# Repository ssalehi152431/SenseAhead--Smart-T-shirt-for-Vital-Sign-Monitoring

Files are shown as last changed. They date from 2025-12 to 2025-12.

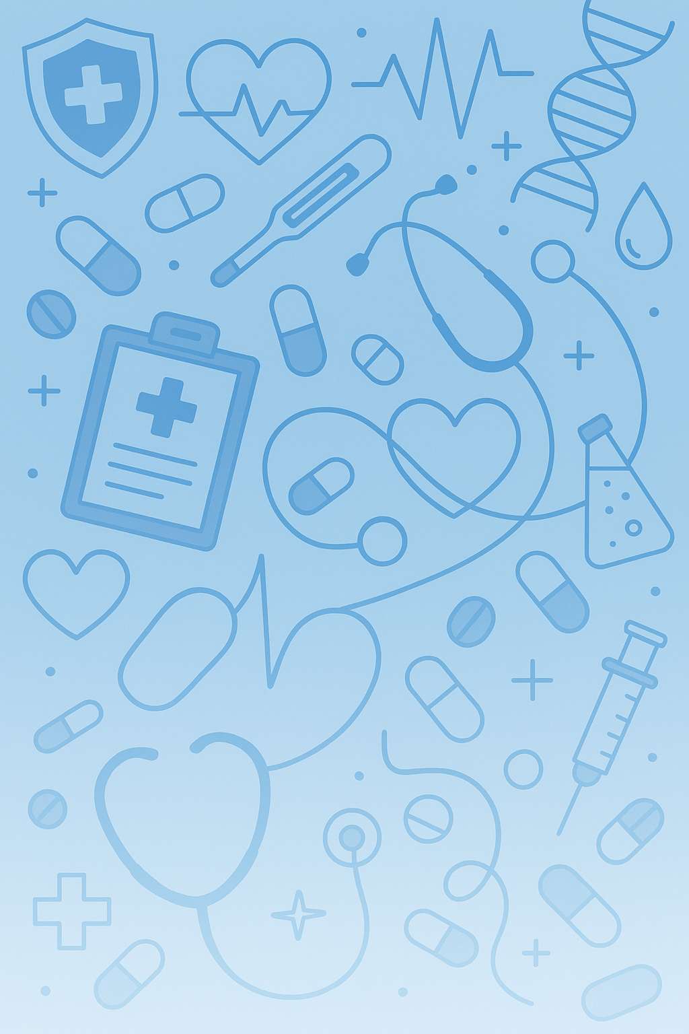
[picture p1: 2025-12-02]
webpage/images/background.png

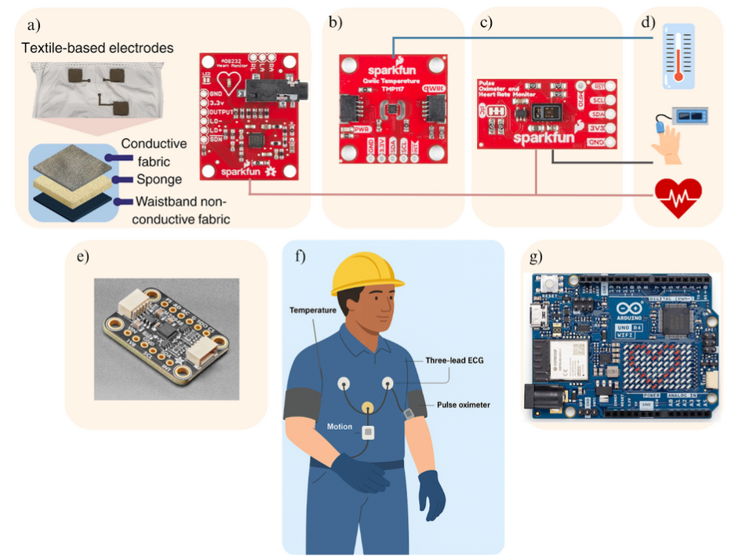
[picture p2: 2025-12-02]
images/Fig 3.png

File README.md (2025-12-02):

# SenseAhead Smart Shirt for Occupational Health
# VSM-3 Vital Sign Monitoring System

This repository contains all design, firmware, hardware, and web application files required to run the VSM‑3 wearable system, which collects **ECG, SpO2, IMU, and temperature data** and displays them on a local web dashboard.

## Our Approach
our approach



## Final Product

Tshirt _2
Tshirt _1
Data_collection

---

## 📦 Project Folder Structure

```
V3/
│
├── Bill_of_Materials.xlsx
│
├── CAD Files/                 → 3D printable enclosure components
│   ├── Arduino_ICM_bottom_v5.step
│   ├── Arduino_ICM_top_v5.step
│   ├── MAX_bottom_v2.step
│   ├── MAX_top_v4.step
│   ├── TMP_bottom_v2.step
│   ├── TMP_top_v2.step
│
├── web_arduino_2/             → Arduino firmware for vital-sign sensors
│   └── web_arduino_2.ino
│
└── webpage/                   → Local-only Web Dashboard (no Firebase needed)
    ├── export/
    ├── functions/
    ├── images/
    ├── node_modules/
    ├── public/
    ├── .firebaserc
    ├── .gitignore
    ├── firebase.json
    ├── firestore.indexes.json
    ├── firestore.rules
    ├── package.json
    └── package-lock.json
```

---

# How to Run the VSM‑3 System (USER GUIDE)

This guide explains how **any user** can run the system locally on their laptop and collect vital‑sign data from the wearable shirt.

---

# 1️⃣ Hardware Setup (Wearable Shirt)

### Required Components
- Arduino UNO R4 WiFi  
- MAX30101 (SpO₂ + HR)  
- AD8232 (ECG)  
- TMP117 (Temperature)  
- ICM‑20948 (9‑axis IMU)  
- Jumper wires  
- Enclosure 3D printed parts (from CAD folder)  
- Shirt with embedded sensors (as designed by team)

### Assembly Overview
1. Attach all sensors to the Arduino using Qwiic/I2C and analog ECG connection.  
2. Mount sensors inside the enclosure parts (CAD folder).  
3. Position electrodes on the chest and tighten straps.  
4. Power the system via USB cable to the laptop.

---

# 2️⃣ Upload Arduino Code

1. Open **Arduino IDE**.
2. Open:

```
web_arduino_2/web_arduino_2.ino
```

3. Scroll to the section:

```cpp
//=======Wi fi config========
const char* STA_SSID = "Salehin";
const char* STA_PASS = "GGunited";
```

Change these values to match your **hotspot name + password**.

4. Connect Arduino UNO R4 WiFi with USB.

5. Click:

✔ **Verify**  
✔ **Upload**

6. Open **Serial Monitor @ 115200 baud** and confirm you see lines like:

```
ECG=700   Thr=400   motionScore=0.02   motionQuality=GOOD
```

This confirms the shirt is sending sensor data.

---

# 3️⃣ Launch the Web Dashboard (Local Mode)

The dashboard is located at:

```
V3/webpage/public/index.html
```

### To open the dashboard:

1. Open VS Code  
2. Install the extension **Live Server**
3. Right‑click:

```
webpage/public/index.html
```

4. Select **"Open With Live Server"**

Your browser will open:

```
http://127.0.0.1:5500/webpage/public/index.html
```

---

# 4️⃣ Create User Account (Local Authentication)

1. On the dashboard login page, select **“Create account”**  
2. Enter:
   - Name  
   - Email  
   - Password  
3. Log in  
4. Your dashboard loads with:

- ACC  
- GYR  
- TEMP  
- SpO₂  
- HR  
- ECG waveform (real‑time)  

**This works fully offline (local Firestore emulator).**

---

# 5️⃣ Start Collecting Data

With Arduino running AND dashboard open:

✔ ECG plots appear  
✔ Temperature updates  
✔ SpO₂ shows when finger sensor works  
✔ HR from ECG is averaged  
✔ Motion score reflects IMU activity

---

# 6️⃣ Where Is Data Stored?

Even without Firebase, the dashboard stores data in:

```
webpage/export/
```

If Firebase is connected later, the same data is pushed to Firestore.

---

# 🛠 Developer Notes (for the team)

### If deploying Firebase Functions again:
Only the **project owner** can run:

```
firebase deploy --only functions
```

Other teammates need IAM permission  
**“Service Account User”**  
in Google Cloud.

Normal users running data collection **do NOT need Firebase**.

---

# 👥 Authors

- Artemis Badger  
- Luisa Chavez  
- Marc Dobos  
- Sultanus Salehin  
- Irem Yunculer

---

# 📄 License
This project is for educational use under ECE‑522 (NC State University).

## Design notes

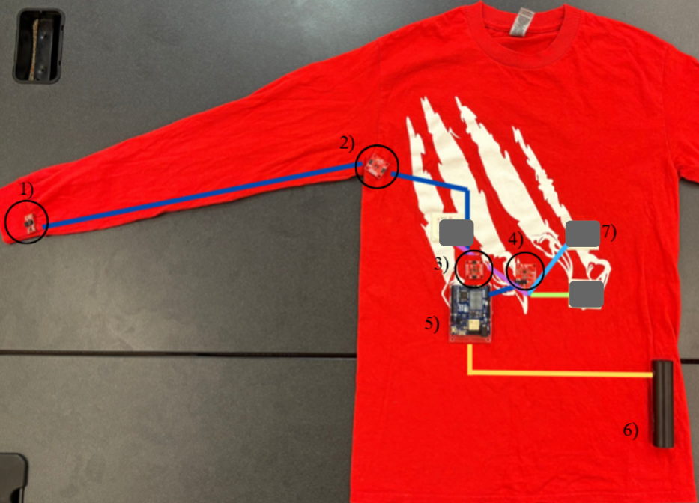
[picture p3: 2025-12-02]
images/Tshirt _1.png

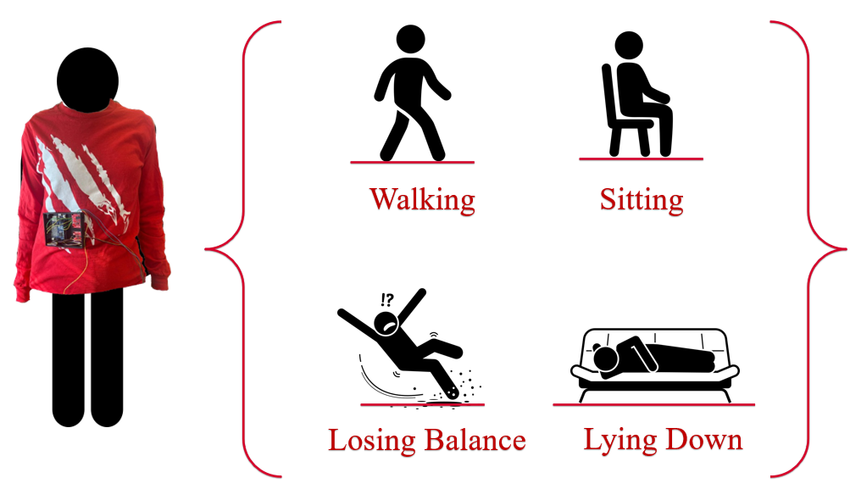
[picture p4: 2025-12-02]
images/Data_collection.png

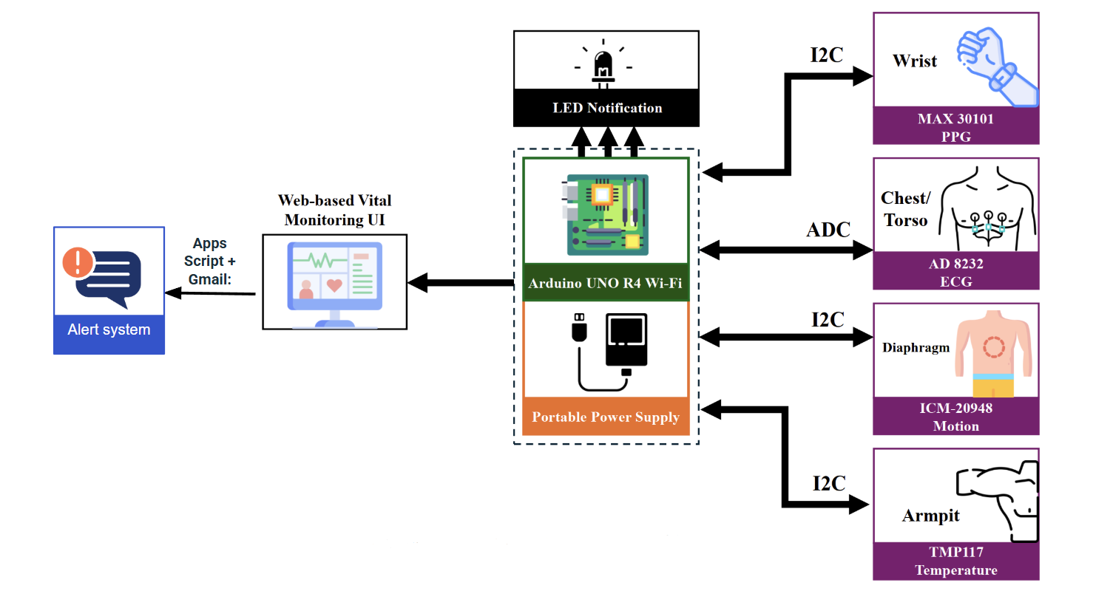
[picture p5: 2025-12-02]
images/our approach.png

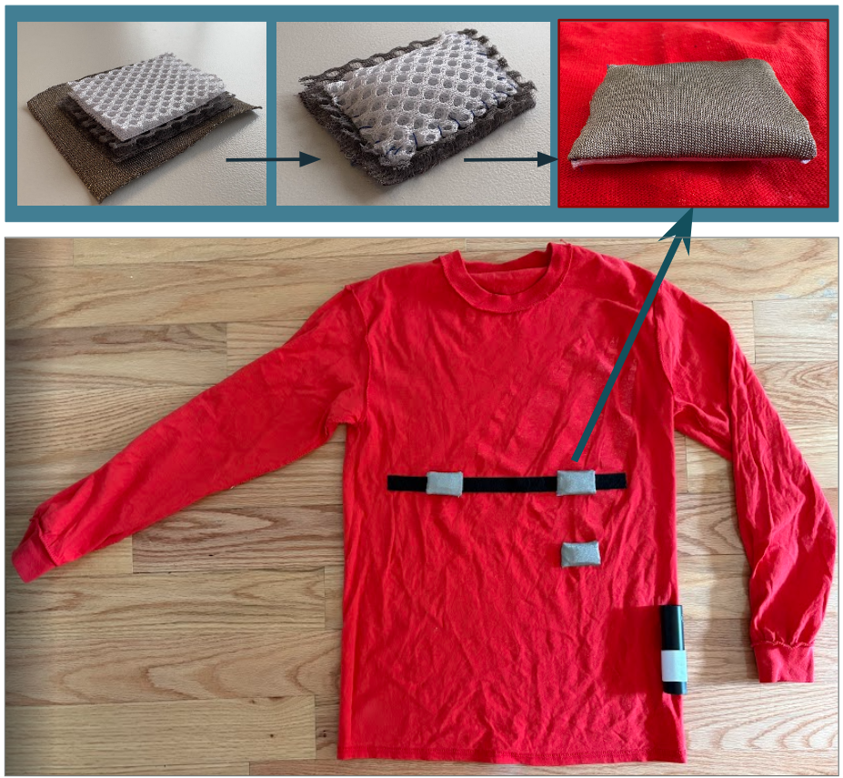
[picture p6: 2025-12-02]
images/Tshirt _2.png

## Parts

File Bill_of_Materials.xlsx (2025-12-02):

VSM-3 Final Bill of Materials
No. | Item Name | Vendor | Vendor Part # | Quantity | Cost per item | Link to Item | Total cost | Notes
1 | AD8232 Heart Rate Monitor | Sparkfun | SEN-12650 | 1 | $24.41 | SparkFun Single Lead Heart Rate Monitor - AD8232 - SparkFun Electronics (https://www.sparkfun.com/sparkfun-single-lead-heart-rate-monitor-ad8232.html) | $24.41
2 | TMP117 Temperature Sensor | Sparkfun | SEN-15850 | 1 | $16.95 | SparkFun High Precision Temperature Sensor - TMP117 (Qwiic) - SparkFun Electronics (https://www.sparkfun.com/sparkfun-high-precision-temperature-sensor-tmp117-qwiic.html) | $16.95
3 | MAX30101 & MAX32664 PPG Sensor | Sparkfun | SEN-15219 | 1 | $48.95 | SparkFun Pulse Oximeter and Heart Rate Sensor - MAX30101 & MAX32664 (Qwiic) - SparkFun Electronics (https://www.sparkfun.com/sparkfun-pulse-oximeter-and-heart-rate-sensor-max30101-max32664-qwiic.html) | $48.95
4 | ICM 20948 9DoF IMU | Sparkfun | SEN-15335 | 1 | $21.95 | SparkFun 9DoF IMU Breakout - ICM-20948 (Qwiic) - SparkFun Electronics (https://www.sparkfun.com/sparkfun-9dof-imu-breakout-icm-20948-qwiic.html) | $21.95
5 | Flexible Qwiix Cable 500mm | Sparkfun | PRT-17257 | 3 | $2.75 | Flexible Qwiic Cable - 500mm - SparkFun Electronics (https://www.sparkfun.com/flexible-qwiic-cable-500mm.html) | $8.25
6 | Jumper Wires M/M | Sparkfun | PRT-09387 | 1 | $4.95 | Jumper Wires Premium 12" M/M Pack of 10 - SparkFun Electronics (https://www.sparkfun.com/jumper-wires-premium-12-m-m-pack-of-10.html) | $4.95
7 | Silver-coated fabric | Amazon | MATYASIGO-US | 1 (dimensions: 0.5mx1.5m) | $27.46 | Amazon.com: silver-coated fabric (https://www.amazon.com/Knitting-Conductive-Radiation-Maternity-0-5MX1-5M/dp/B0B928YJY3) | $27.46
8 | Arduino UNO R4 WiFi | Amazon | ABX00087 | 1 | $27.50 | Amazon.com: Arduino UNO R4 WiFi [ABX00087] – Renesas RA4M1 + ESP32-S3, Wi-Fi, Bluetooth, USB-C, CAN, 12-bit DAC, OP AMP, Qwiic Connector, 12x8 LED Matrix for Advanced IoT & Embedded Projects : Electronics (https://www.amazon.com/Arduino-UNO-WiFi-ABX00087-Bluetooth/dp/B0C8V88Z9D) | $27.50
9 | USB to DC Power Charging Cable | Amazon | USB-DC-001 | 1 | $7.98 | Amazon.com: USB to DC Power Charging Cable with 12pcs DC Barrel Jack Universal Laptop Power Adapter Tips USB 2.0 to DC 5.5x2.1mm Plug Micro USB Type-C Connector Compatible Laptop Camera & More : Electronics (https://www.amazon.com/Charging-Universal-5-5x2-1mm-Connector-Compatible/dp/B0BXPXZMSP) | $7.98
10 | 15000mAh Portable Power Bank | Amazon | P11 | 1 | $12.34 | Amazon.com: LOVELEDI Portable Charger 2-Pack 15000mAh Power Bank Dual USB and Type-C Output 5V3.1A Fast Charger Battery Pack for iPhone 16 15 14 13 12 X Samsung S24 S23 Google iPad etc (Light Black and White) : Cell Phones & Accessories (https://www.amazon.com/dp/B0C4JTVXSK?sp_csd=d2lkZ2V0TmFtZT1zcF9kZXRhaWwy) | $12.34
11 | 3 Rolls Sewing Stretch Elastic Band Spool, 3/5, 1, 1-1/2 Inch in Width, 5.5 Yards/Roll (White) | Amazon | SUNMNS | 1 White Set of 3 rolls (3/5, 1 and 1-1/2 Inch in Width, 5.5 Yards/Roll) | $11.99 | https://www.amazon.com/Sunmns-Rolls-Sewing-Stretch-Elastic/dp/B07J44MP4L | $11.99
12 | SparkFun Photodetector Breakout - MAX30101 | Sparkfun | SEN-16474 | 1 | $34.39 | https://www.sparkfun.com/sparkfun-photodetector-breakout-max30101-qwiic.html#content-features | $34.39
 |  |  |  |  |  | Grand Total: | $247.12

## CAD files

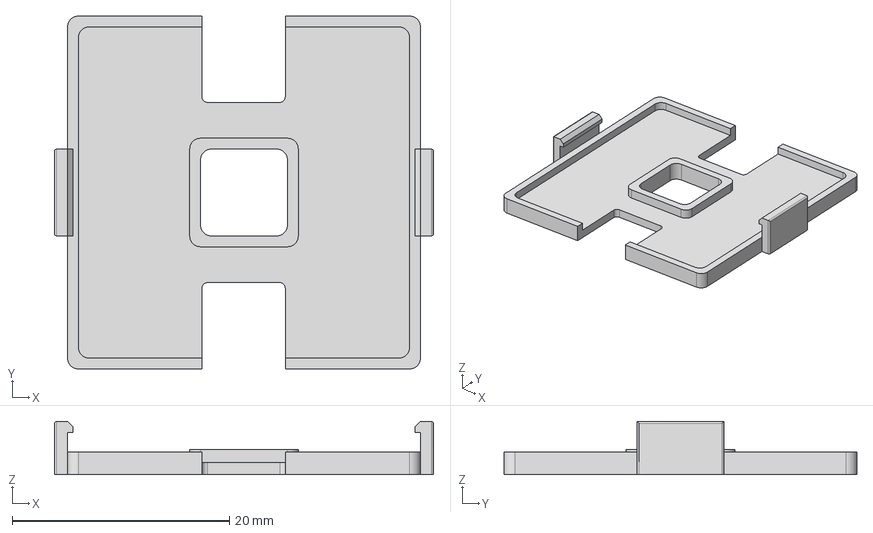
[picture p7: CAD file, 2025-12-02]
CAD Files/TMP_top_v2.step
34.9 x 32.5 x 4.90 mm

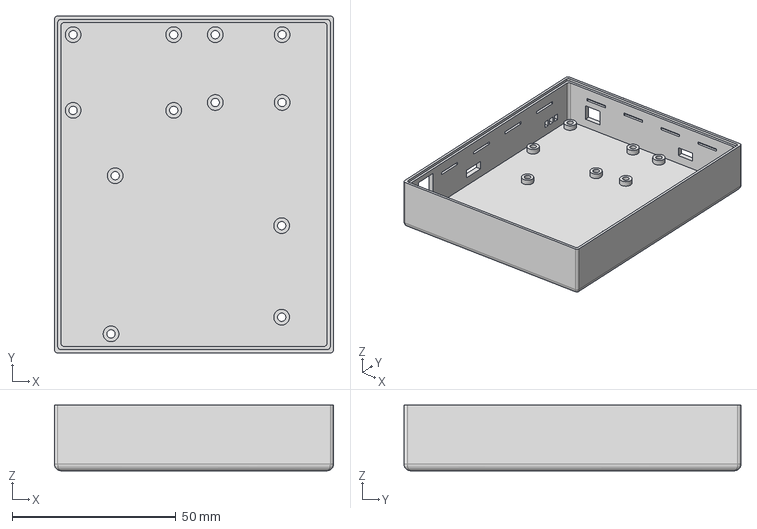
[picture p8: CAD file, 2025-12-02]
CAD Files/Arduino_ICM_bottom_v5.step
85.2 x 102.8 x 20.0 mm

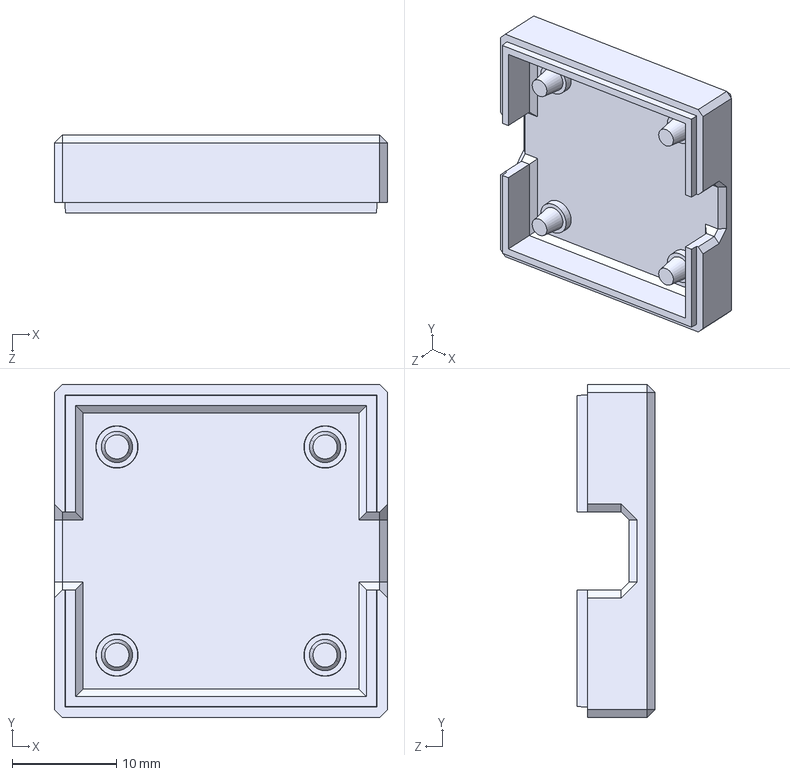
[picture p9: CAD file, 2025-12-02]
CAD Files/MAX_bottom_v2.STEP
32.0 x 32.0 x 7.50 mm

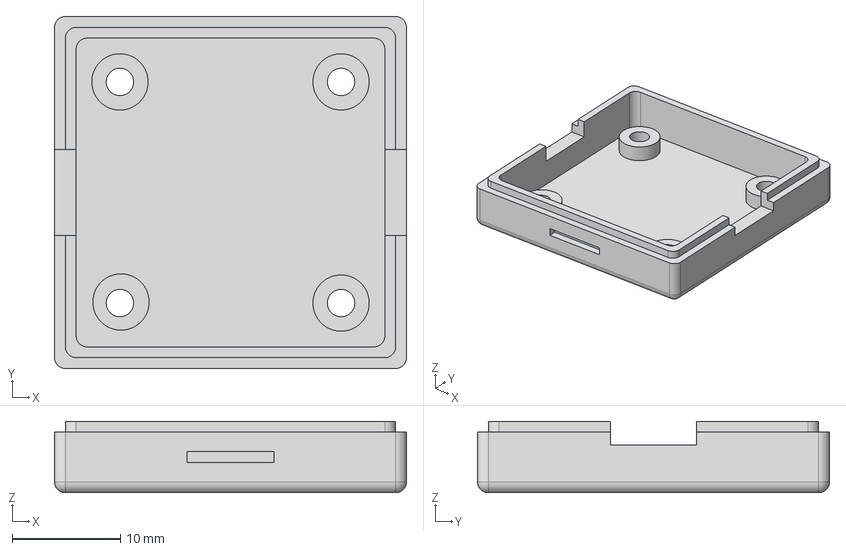
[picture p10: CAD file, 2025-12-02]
CAD Files/TMP_bottom_v2.step
32.5 x 32.5 x 6.60 mm

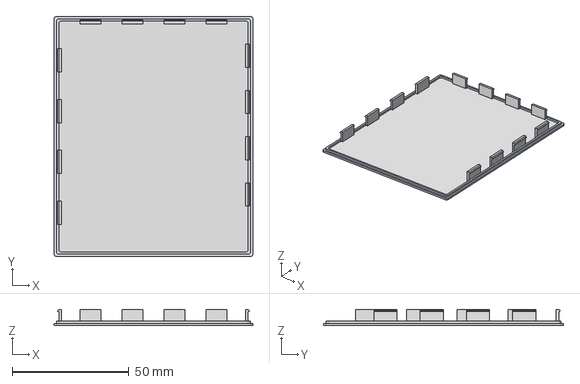
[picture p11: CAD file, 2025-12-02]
CAD Files/Arduino_ICM_top_v5.step
85.2 x 102.8 x 7.00 mm

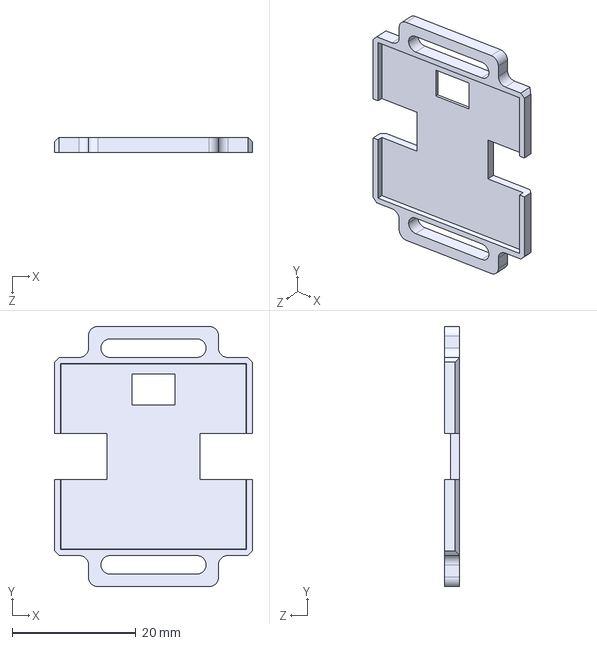
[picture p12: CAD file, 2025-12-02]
CAD Files/MAX_top_v4.STEP
32.0 x 42.0 x 2.50 mm

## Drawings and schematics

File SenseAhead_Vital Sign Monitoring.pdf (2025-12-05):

# SenseAhead Smart Shirt: Wearable Vital Sign Monitoring for Occupational Health and Safety

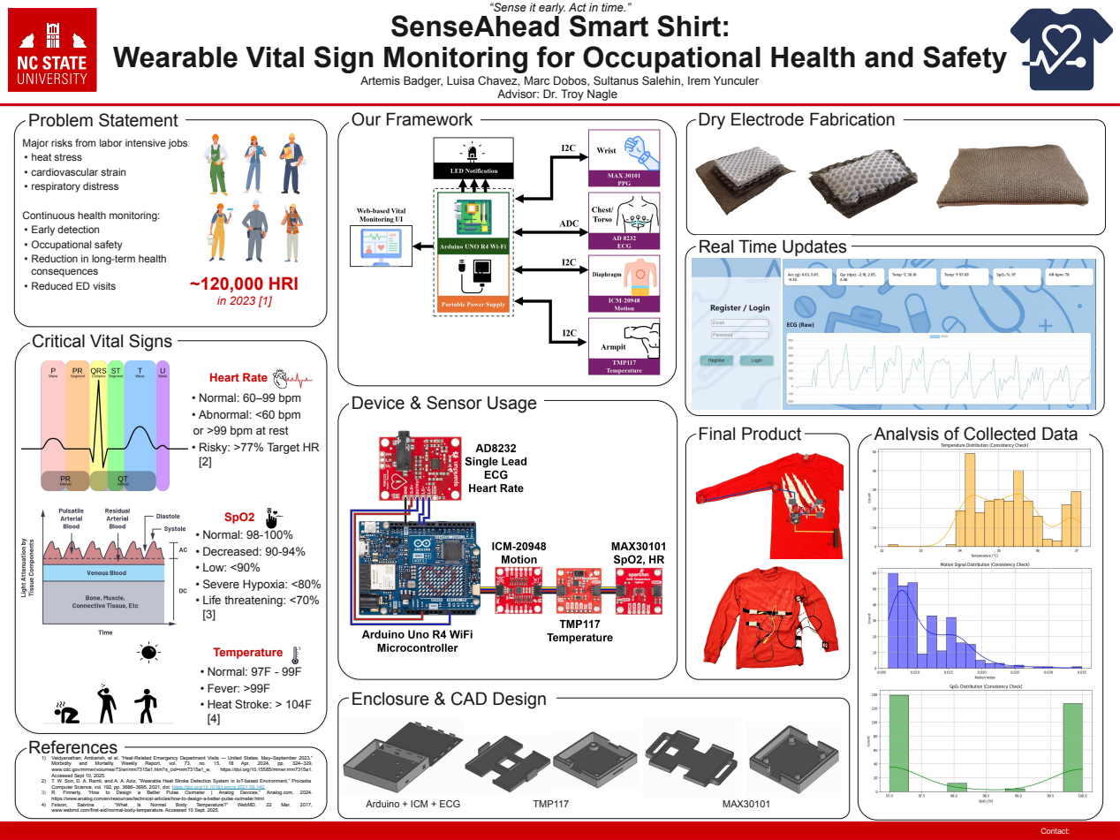
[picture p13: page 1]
Arduino + ICM + ECG; TMP117; MAX30101; Contact:; Problem Statement; Our Framework; References; Final Product; SpO2; Temperature; • Normal: 97F - 99F • Fever: >99F • Heat Stroke: > 104F [4]; ~120,000 HRI; • Normal: 98-100% • Decreased: 90-94% • Low: <90% • Severe Hypoxia: <80% • Life threatening: <70% [3]; Morbidity; and; Mortality; Weekly; Report,; vol.; Apr.; www.cdc.gov/mmwr/volumes/73/wr/mm7315a1.htm?s_cid=mm7315a1_w,; https://doi.org/10.15585/mmwr.mm7315a1.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

“Sense it early. Act in time.”

Artemis Badger, Luisa Chavez, Marc Dobos, Sultanus Salehin, Irem Yunculer

Advisor: Dr. Troy Nagle

Dry Electrode Fabrication

Major risks from labor intensive jobs:
• heat stress
• cardiovascular strain
• respiratory distress

Continuous health monitoring:
• Early detection
• Occupational safety
• Reduction in long-term health
consequences
• Reduced ED visits

Real Time Updates

Critical Vital Signs

Heart Rate
• Normal: 60–99 bpm
• Abnormal: <60 bpm
or >99 bpm at rest
• Risky: >77% Target HR

Device & Sensor Usage

Analysis of Collected Data

Enclosure & CAD Design

1) Vaidyanathan, Ambarish, et al. “Heat-Related Emergency Department Visits — United States, May–September 2023.”
Accessed Sept 10, 2025.
2) T. W. Son, D. A. Ramli, and A. A. Aziz, “Wearable Heat Stroke Detection System in IoT-based Environment,” Procedia
https://www.analog.com/en/resources/technical-articles/how-to-design-a-better-pulse-oximeter.html
www.webmd.com/first-aid/normal-body-temperature. Accessed 10 Sept. 2025.

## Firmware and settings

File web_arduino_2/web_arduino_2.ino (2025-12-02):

#include <WiFiS3.h>
#include <WiFiSSLClient.h>
#include <ArduinoGraphics.h>
#include <Wire.h>
#include <SparkFun_TMP117.h>
#include <ICM_20948.h>
#include <MAX30105.h>
#include "spo2_algorithm.h"   
#include <math.h>
#include <string.h>

//=======Wi fi config========
const char* STA_SSID = "iPhone";
const char* STA_PASS = "5859Irem";

//=======Cloud function===================
const char* CLOUD_HOST = "us-central1-vsm3-741ac.cloudfunctions.net";
const char* CLOUD_INGEST_PATH = "/api/ingest";
const uint16_t HTTPS_PORT = 443;

WiFiServer server(80);

TMP117 tmp117;
ICM_20948_I2C icm;
MAX30105 max30101;
float lastTempC = NAN;
bool max30101_ok = false;

//======ECG =======
const int PIN_ECG_OUT  = A0;
const int PIN_LO_PLUS  = 10;
const int PIN_LO_MINUS = 11;

//=======ECG configuration=======
const float FS_HZ = 250.0f;
const unsigned long TS_US = (unsigned long)(1000000.0f / FS_HZ);
const size_t ECG_BATCH = 250; //1 second per batch
uint16_t ecgBuf[ECG_BATCH];
size_t ecgIdx = 0;
unsigned long next_us = 0;

// ====== ECG detection ======
int ecgValue = 0;
int ecgMin = 1023;
int ecgMax = 0;
int ecgThreshold = 400;

unsigned long lastThreshUpdate = 0;
const unsigned long ECG_WINDOW = 1000;  

unsigned long lastBeatECG = 0;
float bpmECG = 0.0f;
bool ecgAbove = false;

const int N_ECG = 8;
float bpmBuffer[N_ECG];
int bpmIdx = 0;
bool bpmFull = false;

const unsigned long RR_MIN_MS = 580;   // antes 700
const unsigned long RR_MAX_MS = 1300;  // antes 1300
const float        BPM_MIN   = 45.0f;  // antes 45
const float        BPM_MAX   = 100.0f; // antes 90

//=============spo2============
volatile int32_t lastHR = 0;
volatile int32_t lastSpO2 = -1;
volatile int8_t  hrValid = 0;
volatile int8_t  spo2Valid = 0;

// Buffers PPG (IR / RED) 
const uint8_t PPG_BUF_LEN = 100;
uint32_t irBuf[PPG_BUF_LEN];
uint32_t redBuf[PPG_BUF_LEN];
uint8_t  ppgIndex = 0;

bool  spo2HavePrev  = false;
float spo2Prev      = 0.0f;
const float SPO2_ALPHA = 0.7f;

const float SPO2_OFFSET = 16.5f;
const float SPO2_SCALE  = 1.0f;

float lastR = 0.0f;

//======Values======
struct Sample {
  unsigned long ms;
  float acc[3];
  float gyr[3];
} latest;

//========Motion score===========
float accMagEMA = 0.0f;
float motionScore = 0.0f;
const float EMA_ALPHA = 0.05f;
const float MOTION_THRESH = 0.20f;

const float MOTION_GOOD = 0.03f;
const float MOTION_BAD  = 0.20f;

inline float motion_from_acc(const float a[3]) {
  float mag = sqrtf(a[0]*a[0] + a[1]*a[1] + a[2]*a[2]);
  return fabsf(mag - 1.0f);
}

const char* motionQuality() {
  if (motionScore < MOTION_GOOD) return "GOOD";
  if (motionScore > MOTION_BAD)  return "BAD";
  return "MEDIUM";
}

//Simple timing for IMU, ECG, SPO2
unsigned long tIMU = 0;
unsigned long tUpload = 0;
const unsigned long IMU_PERIOD_MS = 50;
const unsigned long UPLOAD_PERIOD_MS = 1000;
const int16_t ECG_OFFSET = 512;

const byte ledBrightness = 47;
const byte sampleAverage = 2;   // 1,2,4,8,16,32
const byte ledMode       = 2;   // 2 = Red+IR
const byte sampleRate    = 100; // Hz
const int  pulseWidth    = 411; // us
const int  adcRange      = 4096;

// ========= Función SpO2 =========
float computeSpO2FromBuffer(const uint32_t* ir, const uint32_t* red, uint8_t len) {
  if (len == 0) return -1.0f;

  double sumIr = 0.0;
  double sumRed = 0.0;
  for (uint8_t i = 0; i < len; i++) {
    sumIr  += (double)ir[i];
    sumRed += (double)red[i];
  }

  double dcIr  = sumIr  / (double)len;
  double dcRed = sumRed / (double)len;

  if (dcIr < 1000 || dcRed < 1000) {
    Serial.println("SpO2: DC muy bajo -> mala colocacion (descartado)");
    return -1.0f;
  }

  // AC = RMS de (x - DC)
  double sumSqIrAC  = 0.0;
  double sumSqRedAC = 0.0;
  for (uint8_t i = 0; i < len; i++) {
    double diffIr  = (double)ir[i]  - dcIr;
    double diffRed = (double)red[i] - dcRed;
    sumSqIrAC  += diffIr  * diffIr;
    sumSqRedAC += diffRed * diffRed;
  }

  double rmsIrAC  = sqrt(sumSqIrAC  / (double)len);
  double rmsRedAC = sqrt(sumSqRedAC / (double)len);

  if (rmsIrAC < 30 || rmsRedAC < 30) {
    Serial.println("SpO2: AC muy pequeno -> sin pulso claro (descartado)");
    return -1.0f;
  }

  // Ratio R = (AC_red/DC_red) / (AC_ir/DC_ir)
  double rIr  = rmsIrAC  / dcIr;
  double rRed = rmsRedAC / dcRed;
  if (rIr <= 0 || rRed <= 0) {
    Serial.println("SpO2: ratio invalido (rIr<=0 o rRed<=0)");
    return -1.0f;
  }

  double R = rRed / rIr;
  lastR = (float)R;

  double spo2 = -45.060 * R * R + 30.354 * R + 94.845;

  Serial.print("DC_IR=");   Serial.print(dcIr, 1);
  Serial.print("  DC_RED=");Serial.print(dcRed, 1);
  Serial.print("  AC_IR="); Serial.print(rmsIrAC, 1);
  Serial.print("  AC_RED=");Serial.print(rmsRedAC, 1);
  Serial.print("  R=");     Serial.print(R, 3);
  Serial.print("  SpO2_raw=");
  Serial.println(spo2, 2);

  if (spo2 < 80.0) spo2 = 80.0;
  if (spo2 > 100.0) spo2 = 100.0;

  return (float)spo2;
}

//================ WiFi & HTTP helpers ==================
void startWiFiSTA() {
  Serial.println("Starting WiFi conection...");
  WiFi.begin(STA_SSID, STA_PASS);
  unsigned long t0 = millis();

  while (WiFi.status() != WL_CONNECTED && millis() - t0 < 15000) {
    Serial.print(".");
    delay(500);
  }

  if (WiFi.status() == WL_CONNECTED) {
    Serial.println("\n Wi-Fi connected!");
    Serial.print("SSID: "); Serial.println(WiFi.SSID());
    Serial.print("IP Address: "); Serial.println(WiFi.localIP());
  } else {
    Serial.println("\n Wi-Fi connection failed.");
    Serial.println("Check SSID/password and ensure 2.4GHz network.");
  }

  server.begin();
}

void sendJsonLatest(WiFiClient &client) {
  client.println("HTTP/1.1 200 OK");
  client.println("Content-Type: application/json");
  client.println("Cache-Control: no-cache");
  client.println("Connection: close");
  client.println("Access-Control-Allow-Origin: *");
  client.println();
  client.print("{\"ms\":"); client.print(latest.ms);
  client.print(",\"acc\":[");
  client.print(latest.acc[0],3); client.print(",");
  client.print(latest.acc[1],3); client.print(",");
  client.print(latest.acc[2],3);
  client.print("],\"gyr\":[");
  client.print(latest.gyr[0],3); client.print(",");
  client.print(latest.gyr[1],3); client.print(",");
  client.print(latest.gyr[2],3);
  if (!isnan(lastTempC)) {
    client.print(",\"tempC\":");
    client.print(lastTempC,2);
  }
  if (hrValid)   { client.print(",\"hr\":");   client.print(lastHR); }     
  if (spo2Valid) { client.print(",\"spo2\":"); client.print(lastSpO2); }
  client.print(",\"motion\":"); client.print(motionScore, 3);
  client.println("]}");
}

void sendTinyHTML (WiFiClient &client) {
  client.println("HTTP/1.1 200 OK");
  client.println("Content-Type: text/html");
  client.println("Cache-Control: no-cache");
  client.println("Connection: close");
  client.println();
  client.println("<!doctype html><html><head><meta charset='utf-8'><meta name='viewport' content='width=device-width,initial-scale=1'>");
  client.println("<title>VSM Device</title></head><body style='font-family:sans-serif'>");
  client.println("<h2>VSM Device</h2>");
  client.println("<p>Use <code>/api/latest</code> for JSON. Your main web UI runs in VS Code.</p>");
  client.println("</body></html>");
}

//======POST JSON a Cloud Function==============
bool postToCloudIngest(const uint16_t* ecg, size_t n) {
  if (WiFi.status() != WL_CONNECTED) return false;

  String payload;
  payload.reserve(128 + n * 4);
  payload += "{\"timestamp\":";
  payload += String((unsigned long)millis());
  payload += ",\"acc\":[";
  payload += String(latest.acc[0], 3) + "," + String(latest.acc[1], 3) + "," + String(latest.acc[2], 3);
  payload += "],\"gyr\":[";
  payload += String(latest.gyr[0], 3) + "," + String(latest.gyr[1], 3) + "," + String(latest.gyr[2], 3);
  payload += "]";
  if (!isnan(lastTempC)) {
    payload += ",\"tempC\":";
    payload += String(lastTempC, 2);
  }
  if (hrValid) {
    payload += ",\"hr\":";
    payload += String(lastHR);      
  }
  if (spo2Valid) {
    payload += ",\"spo2\":";
    payload += String(lastSpO2);
  }

  payload += ",\"ecg\":[";
  for (size_t i = 0; i < n; i++) {
    int16_t centered = (int16_t)ecg[i] - ECG_OFFSET;  
    payload += String(centered);                      
    if (i + 1 < n) payload += ",";
  }
  payload += "],\"motion\":";
  payload += String(motionScore, 3);
  payload += "}";

  WiFiSSLClient https;

  Serial.print("HTTPS connect -> "); Serial.print(CLOUD_HOST); Serial.print(" ... ");
  if (!https.connect(CLOUD_HOST, HTTPS_PORT)) {
    Serial.println("FAIL");
    return false;
  }
  Serial.println("OK");

  https.print(String("POST ") + CLOUD_INGEST_PATH + " HTTP/1.1\r\n");
  https.print(String("Host: ") + CLOUD_HOST + "\r\n");
  https.print("User-Agent: UNO-R4-WiFi\r\n");
  https.print("Content-Type: application/json\r\n");
  https.print("Connection: close\r\n");
  https.print(String("Content-Length: ") + payload.length() + "\r\n\r\n");
  https.print(payload);

  unsigned long t0 = millis();
  String statusLine;
  while (https.connected() && !https.available() && millis() - t0 < 3000) {
    delay(10);
  }
  if (https.available()) {
    statusLine = https.readStringUntil('\n');
    statusLine.trim();
  }

  while (https.available()) { https.read(); }
  https.stop();

  Serial.print("HTTP status: ");
  Serial.println(statusLine);
  return statusLine.indexOf("200") >= 0;
}

//====================SETUP======================
void setup() {
  Serial.begin(115200);
  delay(1000);

  // I2C on Qwiic
  Wire1.begin();
  Wire1.setClock(400000);

  // ICM-20948
  Serial.println("ICM-20948 init...");
  if (icm.begin(Wire1, 0x69) != ICM_20948_Stat_Ok) {
    Serial.println("ICM not found");
    while (1);
  } else {
    Serial.println("ICM OK");
  }

  // ECG
  pinMode(PIN_LO_PLUS, INPUT);
  pinMode(PIN_LO_MINUS, INPUT);

  // TMP117
  Serial.println("TMP117 init...");
  if (!tmp117.begin(0x48, Wire1)) {
    Serial.println("TMP117 not found");
  } else {
    Serial.println("TMP117 OK");
    tmp117.setConversionAverageMode(3); //for noise
  }

  // SpO2 (MAX30101)
  Serial.println("MAX30101 init...");
  if (max30101.begin(Wire1, I2C_SPEED_FAST)) {
    max30101.setup(ledBrightness, sampleAverage, ledMode, sampleRate, pulseWidth, adcRange);
    max30101.setPulseAmplitudeRed(ledBrightness);
    max30101.setPulseAmplitudeIR(ledBrightness);
    Serial.println("MAX30101 OK");
    max30101_ok = true;
  } else {
    Serial.println("MAX30101 not found (continuing without SpO2).");
    max30101_ok = false;
  }

  // WiFi
  startWiFiSTA();

  latest.ms = millis();
  latest.acc[0] = latest.acc[1] = latest.acc[2] = 0;
  latest.gyr[0] = latest.gyr[1] = latest.gyr[2] = 0;

  ecgMin = 1023;
  ecgMax = 0;
  lastThreshUpdate = millis();
  for (int i = 0; i < N_ECG; i++) bpmBuffer[i] = 0;

  Serial.println("Ready");
}

//====================LOOP======================
void loop() {
  const unsigned long now_ms = millis();
  const unsigned long now_us = micros();
  static unsigned long tTemp = 0;

  //======== IMU =========
  if (now_ms - tIMU >= IMU_PERIOD_MS) {
    tIMU = now_ms;
    if (icm.dataReady()) {
      icm.getAGMT();
      latest.acc[0] = icm.accX() / 1000.0f;
      latest.acc[1] = icm.accY() / 1000.0f;
      latest.acc[2] = icm.accZ() / 1000.0f;
      latest.gyr[0] = icm.gyrX();
      latest.gyr[1] = icm.gyrY();
      latest.gyr[2] = icm.gyrZ();
    }
    latest.ms = now_ms;
    float m = motion_from_acc(latest.acc);
    accMagEMA = (1.0f - EMA_ALPHA) * accMagEMA + EMA_ALPHA * m;
    motionScore = accMagEMA;
  }

  const char* mQuality = motionQuality();

  //======== ECG =========
  if ((long)(now_us - next_us) >= 0) {
    next_us += TS_US;

    if (digitalRead(PIN_LO_PLUS) == HIGH || digitalRead(PIN_LO_MINUS) == HIGH) {
      return;   
    }

    uint16_t sample = analogRead(PIN_ECG_OUT);

    if (sample <= 5 || sample >= 1018) {
      return;
    }

    ecgBuf[ecgIdx++] = sample;
    if (ecgIdx >= ECG_BATCH) ecgIdx = 0;

    ecgValue = sample;
    unsigned long now = millis();

    if (lastBeatECG != 0 && (now - lastBeatECG > 4000)) {
      hrValid     = 0;
      lastBeatECG = 0;   
    }

    if (ecgValue < ecgMin) ecgMin = ecgValue;
    if (ecgValue > ecgMax) ecgMax = ecgValue;

    if (now - lastThreshUpdate > ECG_WINDOW) {
      int amp = ecgMax - ecgMin;
      if (amp > 20) {
        ecgThreshold = ecgMin + 0.3 * amp;
      }
      Serial.print("ecgMin="); Serial.print(ecgMin);
      Serial.print(" ecgMax="); Serial.print(ecgMax);
      Serial.print(" amp=");    Serial.print(amp);
      Serial.print(" -> Thr="); Serial.println(ecgThreshold);

      ecgMin = 1023;
      ecgMax = 0;
      lastThreshUpdate = now;
    }

    bool ecgSignalOk    = (ecgThreshold > 150 && ecgThreshold < 900);
    bool pocoMovimiento = true; 

    if (pocoMovimiento &&
        ecgSignalOk &&
        !ecgAbove &&
        ecgValue > ecgThreshold) {

      ecgAbove = true;
      unsigned long nowBeat = now;

      if (lastBeatECG == 0 || (now - lastBeatECG > 2000)) {
        lastBeatECG = nowBeat;
        Serial.print("PICO: ecg="); Serial.print(ecgValue);
        Serial.print(" thr=");      Serial.print(ecgThreshold);
        Serial.println("  -> primer latido / reinicio RR");
      } else {
        unsigned long rr = nowBeat - lastBeatECG;

        Serial.print("PICO: ecg="); Serial.print(ecgValue);
        Serial.print(" thr=");      Serial.print(ecgThreshold);
        Serial.print(" rr=");       Serial.print(rr);

        float inst = 60000.0f / rr;   
        Serial.print(" instBPM="); Serial.print(inst);

        bool okRR  = (rr  >= RR_MIN_MS && rr  <= RR_MAX_MS);
        bool okBPM = (inst >= BPM_MIN   && inst <= BPM_MAX);

        if (!okRR) {
          Serial.println("  -> RR fuera de rango (latido ignorado)");
        }
        else if (!okBPM) {
          Serial.println("  -> BPM fuera de rango (latido ignorado)");
        }
        else {
          lastBeatECG = nowBeat;  

          bpmBuffer[bpmIdx] = inst;
          bpmIdx++;
          if (bpmIdx >= N_ECG) { bpmIdx = 0; bpmFull = true; }

          int   count = bpmFull ? N_ECG : bpmIdx;
          float sum   = 0;
          for (int i = 0; i < count; i++) sum += bpmBuffer[i];
          bpmECG = sum / count;

          lastHR  = (int32_t)round(bpmECG);
          hrValid = 1;

          Serial.print("  -> LATIDO ACEPTADO  (HR_ECG_prom=");
          Serial.print(bpmECG);
          Serial.println(")");
        }
      }
    }

    if (ecgAbove && ecgValue < ecgThreshold - 5) {
      ecgAbove = false;
    }
  }

  //======== TEMP =========
  if (millis() - tTemp >= 100) {
    tTemp = millis();
    if (tmp117.dataReady()) {
      lastTempC = tmp117.readTempC();
    }
  }

  //======== SPO2 =========
  if (max30101_ok && max30101.check()) {
    while (max30101.available()) {
      uint32_t ir  = max30101.getIR();
      uint32_t red = max30101.getRed();
      max30101.nextSample();

      irBuf[ppgIndex]  = ir;
      redBuf[ppgIndex] = red;
      ppgIndex++;

      if (ppgIndex >= PPG_BUF_LEN) {
        Serial.println("************* VENTANA COMPLETA (100 muestras) *************");
        ppgIndex = 0;

        float spo2Raw = computeSpO2FromBuffer(irBuf, redBuf, PPG_BUF_LEN);
        bool lowMotion = (motionScore < MOTION_THRESH);

        Serial.println("-------------------------------------------------");
        Serial.print("SpO2 crudo (ventana): ");
        Serial.print(spo2Raw, 2);
        Serial.print(" | R = ");
        Serial.print(lastR, 3);
        Serial.print(" | motionScore = ");
        Serial.print(motionScore, 3);
        Serial.print(" (");
        Serial.print(lowMotion ? "BAJO" : "ALTO");
        Serial.println(" movimiento)");

        if (spo2Raw > 0 && spo2Raw <= 100 && lowMotion) {
          float spo2Cal = SPO2_SCALE * spo2Raw + SPO2_OFFSET;
          if (spo2Cal > 100.0f) spo2Cal = 100.0f;
          if (spo2Cal < 70.0f)  spo2Cal = 70.0f;

          Serial.print("SpO2 calibrado (antes de suavizar) = ");
          Serial.println(spo2Cal, 2);

          if (!spo2HavePrev || fabs(spo2Cal - spo2Prev) > 3.0f) {
            spo2Prev     = spo2Cal;
            spo2HavePrev = true;
          } else {
            spo2Prev = SPO2_ALPHA * spo2Cal + (1.0f - SPO2_ALPHA) * spo2Prev;
          }

          int spo2Smooth = (int)round(spo2Prev);

          lastSpO2  = spo2Smooth;
          spo2Valid = 1;

        } else {
          spo2Valid = 0;
        }

      }
    }
  }

  //======== UPLOAD TO CLOUD – CADA ~5 s =========
  const unsigned long UPLOAD_PERIOD_MS_NEW = 5000;
  if (WiFi.status() == WL_CONNECTED &&
      (now_ms - tUpload >= UPLOAD_PERIOD_MS_NEW) &&
      ecgIdx > 0) {

    bool ok = postToCloudIngest(ecgBuf, ecgIdx);
    Serial.println(ok ? "Upload ECG+SPO2: OK" : "Upload ECG+SPO2: FAIL");
    ecgIdx = 0;
    tUpload = now_ms;
  }

  // ---------- HTTP local debug ----------
  WiFiClient client = server.available();
  if (client) {
    String line = "";
    bool firstLine = true;
    String reqLine;

    while (client.connected()) {
      if (!client.available()) continue;
      char c = client.read();
      line += c;

      if (c == '\n') {
        if (firstLine) { reqLine = line; firstLine = false; }
        if (line == "\r\n" || line == "\n") {
          if (reqLine.startsWith("GET /api/latest")) {
            sendJsonLatest(client);
          } else {
            sendTinyHTML(client);
          }
          break;
        }
        line = "";
      }
    }
    client.stop();
  }
  Serial.print("ECG=");
  Serial.print(ecgValue);
  Serial.print("  Thr=");
  Serial.print(ecgThreshold);
  Serial.print("  motionScore=");
  Serial.print(motionScore,3);
  Serial.print("  motionQuality=");
  Serial.println(motionQuality());

  delay(5);
}
